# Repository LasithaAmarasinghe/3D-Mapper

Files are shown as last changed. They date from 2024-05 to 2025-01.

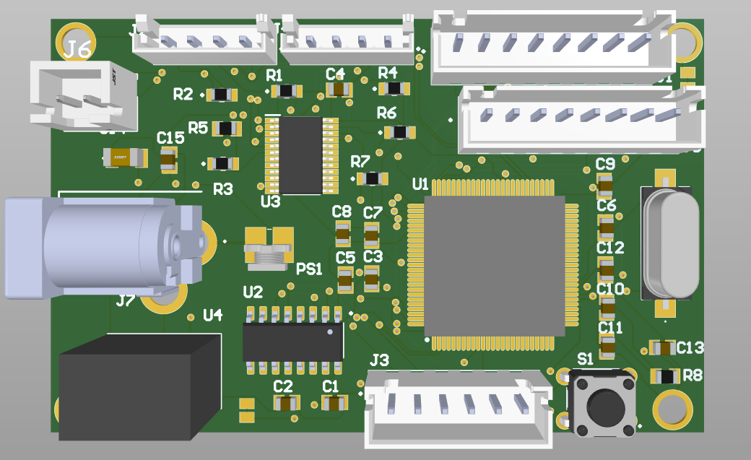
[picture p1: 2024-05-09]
PCB design/3D view.png

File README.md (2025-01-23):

# 3D-Mapper 
* 3D-Mapper is a 3D plotting device made for short-range object detection powered by [ATmega 2560](https://github.com/LasithaAmarasinghe/3D-Mapper/blob/main/data%20sheets/ATMEGA2560.PDF).
* This is developed for the semester 4 project under EN 2160: Electronic Design Realization.


## Working Principle 

* This device measures distances to objects using two Time-of-Flight (TOF) sensors, which are rotated by two stepper motors to cover the entire 3D environment.
* The distance values are saved in (r, theta, alpha) coordinates and then converted to (x, y, z) coordinates.
* Using the [PyVista](https://github.com/pyvista) library in Python, a 3D point cloud is generated from these cartesian coordinates. 
* A tetrahedral mesh is created by performing [3D Delaunay triangulation](https://github.com/LasithaAmarasinghe/3D-Mapper/blob/main/3D%20Delaunay%20Triangulation.pdf) on the point cloud.
* Then the outer surface of this tetrahedral mesh is extracted to form a surface mesh.

## Why "3D-Mapper"?

* Precision in Short-Range Mapping
* Comprehensive Coverage
* Cost-Effective
* Scalability and Customization
* Versatility Across Industries

## Areas of Opportunity

* Emerging Technology Integration - Enhance capabilities with AI and machine learning.
* Market Expansion - Adapt for use in virtual reality (VR) & augmented reality (AR) to access new and growing markets.
* Data Analytics Enhancement - Develop advanced software for better data analysis and visualization, adding value and creating new revenue streams.

## Hardware Specifications

* [ATmega2560](https://github.com/LasithaAmarasinghe/3D-Mapper/blob/main/data%20sheets/ATMEGA2560.PDF)
* [CH340C USB to Serial Chip](https://github.com/LasithaAmarasinghe/3D-Mapper/blob/main/data%20sheets/CH340C%20USB%20to%20serial%20chip.PDF)
* [I2C Multiplexer](https://github.com/LasithaAmarasinghe/3D-Mapper/blob/main/data%20sheets/tca9548a%20I2C%20multiplexer.pdf)
* [Nema 17 Stepper Motors](https://github.com/LasithaAmarasinghe/3D-Mapper/blob/main/data%20sheets/NEMA17%20Stepper%20Motor.PDF)
* [Micro Step Motor Drivers](https://github.com/LasithaAmarasinghe/3D-Mapper/blob/main/data%20sheets/TB6600-Micro%20Step%20Stepper-Motor-Driver.pdf)
* [TOF Sensors](https://github.com/LasithaAmarasinghe/3D-Mapper/blob/main/data%20sheets/TOF.png)
* [12V to 5V Buck Converter](https://github.com/LasithaAmarasinghe/3D-Mapper/blob/main/data%20sheets/R_78CK_0_5-DC_DC%20Converter.pdf)

## Software Specifications

* Arduino IDE
* Solid Works
* Altium
* Python 











## PCB Design



## PCB 

PCB

## Solidworks Design

solidworks
Interior Design
Side view

## Team

team

## For More Information  

- **[Design Document](Design_Document.pdf)**
- **[Design Methodology Report](Design_Methodology_Report.pdf)**

## License
 
 * This project is licensed under the MIT License. See the [LICENSE](MIT-LICENSE.txt) file for details.

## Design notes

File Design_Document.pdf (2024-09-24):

# Department of Electronic & Telecommunication

Engineering,
University of Moratuwa, Sri Lanka.

# 3D Mapping Device for Object Tracking Design Documentation - Group B

# Submitted By:

210728C Wijewickrama W.K.D.D.D. 210031H Amarasinghe A.A.W.L.R.

## Submitted in partial fulfillment of the requirements for the module

# EN 2160 : Electronic Design Realization

## 7th July 2024

EN2160 | Design Documentation : Group B

# Contents

1 Introduction | 3
2 Component Selection and Justifications | 4
3 Schematic Design | 17
4 PCB Design | 26
5 Enclosure Design | 31
6 Detailed Programming Information | 40
7 Photographs | 62
8 References | 80

1

9 Signed Declaration | 81
10 Appendix | 82

2

# 1 Introduction

The 3D Scanner device represents a cutting-edge solution for precise and efficient three-dimensional data acquisition in various applications. This design document comprehensively outlines the component selection process and daily progress of the project. It encapsulates the combined work of our multi-disciplinary team, leveraging expertise in optical engineering, electronics, software development, and human-centered design principles.
The device features a Time-of-Flight (ToF) sensor designed for precise measurement of distances and angles. It utilizes UART communication via ATMEGA 2560 microcontroller pins connected to a USB-to-Serial converter, enabling seamless interfacing with computers equipped with USB ports for data transmission and visualization. This setup ensures efficient handling of distance measurement data and robust communication capabilities, making the device suitable for applications requiring

## accurate spatial data acquisition and analysis

3

# 2 Component Selection and Justifications

## 2.1 Microcontroller

## ATMEGA 2560 MCU

- The ATMEGA 2560 microcontroller unit (MCU) was selected as the central processing unit for the 3D surround scanner. This microcontroller was chosen for its adequate memory, processing speed, and overall reliability.

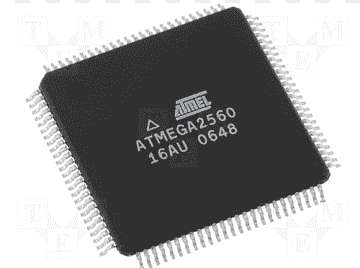
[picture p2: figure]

## Figure 1: ATmega 2560

## Specifications:

## - High Performance, Low Power AVR® 8-Bit Microcontroller

## - Advanced RISC Architecture

## - Non-volatile Program and Data Memories

## - JTAG (IEEE std. 1149.1 compliant) Interface

## - 51/86 Programmable I/O Lines

## - Temperature Range: -40°C to 85°C Industrial

## Key Features:

## - Memory: The ATMEGA 2560 offers 256 KB of Flash memory, 8 KB of SRAM, and 4 KB of

EEPROM, providing sufficient space for handling the initial stages of data processing.

## - Processing Speed: It operates at a clock speed of 16 MHz, which meets the demands of

real-time data collection and processing required for the 3D mapper.

- Reliability: Known for its stable performance, the ATMEGA 2560 is widely used in various applications, making it a dependable choice for our project.

4

## Reasons for Selection:

- Versatility: The ATMEGA 2560 supports a wide range of peripherals and interfaces, making it adaptable to various components used in the 3D mapper project.

## - Community Support: The ATMEGA 2560 has extensive documentation and a large commu-

nity of users, providing valuable resources and support for troubleshooting and development.

- Cost-Effective: Compared to other microcontrollers with similar capabilities, the ATMEGA 2560 offers a good balance between performance and cost, making it an economical choice for the project.

## - Ease of Programming: The microcontroller is compatible with the Arduino platform, which

simplifies programming and prototyping, allowing for faster development cycles.

- Proven Track Record: The ATMEGA 2560 has been used in numerous successful projects, indicating its reliability and robustness in real-world applications.

Despite these advantages, the memory capacity of the ATMEGA 2560 was insufficient to store the entire dataset generated during the scanning process. Therefore, the data readings had to be transmitted incrementally to a connected computer for further processing and storage.

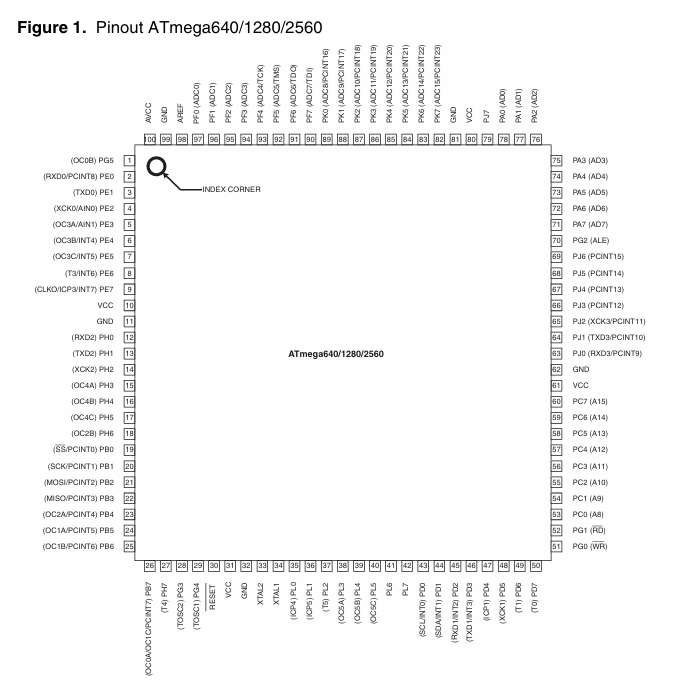
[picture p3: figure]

## Figure 2: ATmega2560

5

## 2.2 Time-of-Flight (ToF) Sensors

## VL53L0 ToF Sensors

- Two Time-of-Flight sensors were selected for the 3D mapper to measure the distance of objects with high precision and speed.

## Figure 3: TOF

## Specifications

- VDD: Regulated 2.8 V output. Almost 150 mA available to power external components.
- VIN: The main 2.6 V to 5.5 V power supply connection. The SCL and SDA level shifters pull the I2C wire high to this level.

## - GND: The ground (0 V) connection for power supply. I2C control source must also share a

common ground with this board.

- SDA: Level-shifted I2C data line; HIGH is VIN, LOW is 0 V.
- SCL: Level-shifted I2C clock line; HIGH is VIN, LOW is 0 V.

## - XSHUT: This pin is an active-low shutdown input; the board pulls it up to VDD to enable

the sensor by default.

## Reasons for Selection:

- High Precision: ToF sensors are capable of measuring distances accurately, which is crucial for creating a detailed 3D map.
- Speed: These sensors can take measurements rapidly, enabling real-time data collection and processing.
- Range: ToF sensors can cover a sufficient range suitable for the intended mapping application.

6

## 2.3 I2C Multiplexer

## TCA9548A

- An I2C multiplexer was used to connect the two ToF sensors to the ATMEGA 2560.

## Figure 4: TCA9548A

## Specifications:

## - 1-to-8 Bidirectional Translating Switches

## - I2C Bus and SMBus Compatible

## - Allows Voltage-Level Translation Between 1.8-V, 2.5-V, 3.3-V, and 5-V Buses

## - Operating Power-Supply Voltage Range of 1.65-V to 5.5-V

## - Low RON Switches

## Reasons for Selection:

## - Multiple I2C Devices: The multiplexer allows multiple I2C devices to be connected to a

single I2C bus, expanding the number of sensors that can be used simultaneously.

- Simplifies Wiring: Reduces the complexity of wiring by allowing easy addition of sensors without requiring additional I2C ports on the microcontroller.

## - Efficient Communication: Ensures efficient communication between the microcontroller

and the sensors, maintaining the integrity and speed of data transfer.

7

## 2.4 USB Serial Communication

## CH340C

## - The CH340C chip was chosen for USB serial communication between the ATMEGA 2560 and

the connected computer.

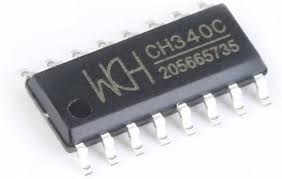
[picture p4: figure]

## Figure 5: CH340C

## Specifications:

## - Full-speed USB device interface, compatible with USB V2.0

## - Fully compatible with serial port applications

## - Supports common MODEM contact signals

## - Provides RS232, RS485, RS422 interfaces

## - Supports 5V and 3.3V power supply voltages

## Reasons for Selection:

- Reliable Communication: Provides a reliable interface for serial communication over USB, essential for transmitting data to the computer for further processing.
- Compatibility: Compatible with a wide range of operating systems, ensuring ease of integration and use.
- Cost-Effective: The CH340C is a cost-effective solution for USB to serial conversion, making it an economical choice for the project.

8

## 2.5 Stepper Motor

## Nema 17HS4401

- The NEMA 17HS4401 stepper motor is renowned for its versatility and reliability in various

## applications requiring precise motion control

## Figure 6: Nema 17

## Specifications

- Holding Torque: 0.35 Nm at continuous current, 0.5 Nm at peak current.
- Continuous Output Current: 1.8 A.
- Step Angle: 1.8°.
- Rotor Inertia: 57 g·cm².
- Weight: 0.37 kg.

## Reasons for Selection

1. Compact Size: Suitable for applications with limited space, such as 3D printers and small CNC machines.
2. Moderate Torque: Provides adequate torque (0.35 Nm continuous, 0.5 Nm peak) for precise motion control and handling moderate loads.
3. Precise Control: 1.8° step angle and high subdivision accuracy (1–32 steps) enable fine resolution and accurate positioning.
4. Versatility: Compatible with various driver modules and control systems, offering flexibility in design and integration.
5. Cost-Effectiveness: Balances performance and cost effectiveness, making it a practical choice for both industrial and DIY projects.
6. Reliability: Known for robust construction and durability, ensuring reliable performance in demanding environments.
7. Availability: Widely available from multiple manufacturers, providing easy access to parts and support.

9

## Calculation for Selection

10

11

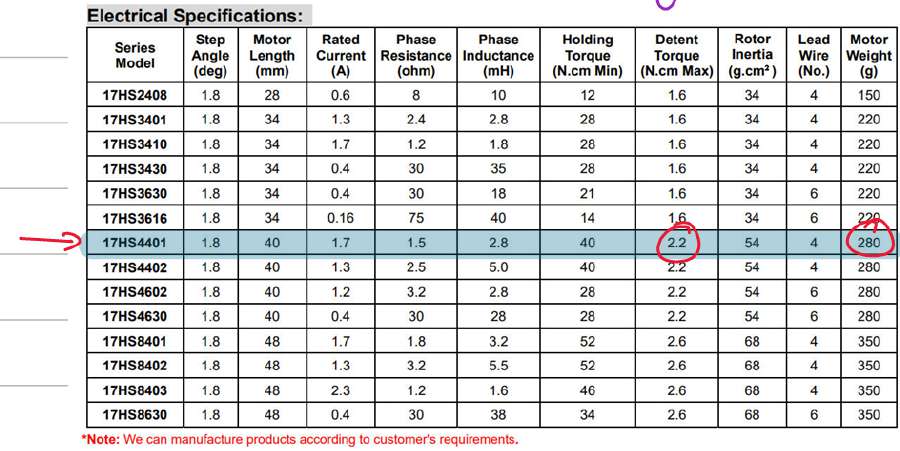
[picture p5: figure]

## Figure 7: Nema17 Motor Comparision

Other constraints of choosing a suitable stepper motor were availability and price within budget. So we decided Nema 17HS4401 as the best option for the 3D scanner considering all the factors.

12

## 2.6 Stepper Motor Driver

TB6600
- The TB6600 stepper motor driver is a versatile choice for controlling stepper motors in various applications. It offers a range of features suitable for precise and powerful motor control, making it ideal for both industrial and DIY projects.

## Figure 8: TB6600

## Specifications:

## - Model: TB6600

## - Compatible Motors: Nema 17/23/34 (42/57/86 Stepper Motor)

## - Control Signal: 3.3VDC–24VDC

## - Subdivision Accuracy: 1–32

## - Output Current: 4A

## - Voltage: 9VDC–40VDC

## Reasons for Selection:

- Motor Compatibility: Compatible with Nema 17, 23, 34 motors.
- Output Current: Up to 4A for sufficient torque.
- Voltage Range: Supports 9VDC–40VDC for flexible power options.
- Subdivision Accuracy: Precision from 1–32 steps.
- Control Signal: Compatible with 3.3VDC–24VDC signals.
- Reliability: Known for robust performance in industrial applications.

13

## 2.7 Power Step-Down

## R-78CK-0.5 12V-5V

## - A 12V-5V power step-down module was used to supply power to the ATMEGA 2560 and other

components.

## Figure 9: R-78CK-0.5

## Specifications

## - Efficiency up to 96%

## - Pin-out compatible with LM78xx linears

## - Compact package

## - Wide input range (5V - 40V)

## - Short circuit protection, thermal shutdown

## - Low ripple and noise

## Reasons for Selection:

- Voltage Regulation: Ensures stable voltage supply to the microcontroller and sensors, which is crucial for reliable operation.
- Efficiency: High efficiency in converting 12V input to 5V output, minimizing power loss and heat generation.
- Compact Size: The module is compact, making it easy to integrate into the overall design without adding significant bulk.

14

## 2.8 Clock Oscillator

## 16 MHz Crystal Oscillator

- A 16 MHz crystal oscillator was used to provide the clock signal for the ATMEGA 2560.

## Figure 10: oscillator

## Specifications

## - Model: HC49/4HSMX

## - Frequency: 16 MHz

## - Load Capacitance: 22 pF

## - Shunt Capacitance: 7pF max

## - Tolerance: 30 PPM

## - Frequency Stability: 50 PPM

## - Overtone Order: Fundamental

## Reasons for Selection:

## - Precision Timing: Provides a stable and precise clock signal necessary for the accurate

operation of the microcontroller.

- Frequency Stability: Ensures consistent performance of the microcontroller by maintaining a stable clock frequency.

## - Compatibility: Specifically chosen to match the operational requirements of the ATMEGA

2560.

15

## 2.9 Decoupling Capacitors

## 100µF Decoupling Capacitors

- 100µF decoupling capacitors were used to stabilize the power supply to the microcontroller and other components.

## Figure 11: capacitor

## Reasons for Selection:

- Noise Reduction: Help to filter out noise and prevent voltage spikes, ensuring a stable power supply.

## - Improved Performance: Enhances the overall performance and reliability of the microcon-

troller by maintaining a clean power signal.

- Protection: Protects sensitive components from transient voltage fluctuations.

## 2.10 Pull-up Resistors

## 2.2k Resistors

- 2.2k resistors were used in the I2C lines to ensure proper signal levels.

## Figure 12: resistor

## Reasons for Selection:

- Pull-up Function: These resistors act as pull-up resistors for the I2C bus, ensuring that the lines are correctly biased and that signals are accurately interpreted.
- Signal Integrity: Maintains the integrity of the I2C signals, preventing erroneous data transmission.
- Standard Value: 2.2k ohms is a standard value for pull-up resistors in I2C communication, ensuring compatibility and reliable operation.

16

# 3 Schematic Design

The schematic design for the overall system was developed using the Altium Designer EDA platform. To ensure an organized and efficient design process, we adopted a hierarchical design methodology,

## emphasizing modularity and abstraction where we identified four main sub-parts:

## 1. Microcontroller Circuit

## 2. USB Port Circuit

## 3. I2C Multiplexer Circuit

## 4. Power Supply Circuit

## 3.1 System Overview

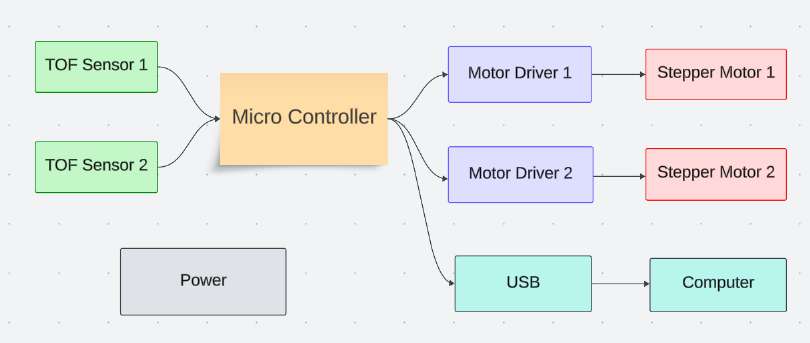
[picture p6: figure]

## Figure 13: block diagram

## The system consists of the following components and their interactions:

## - Microcontroller:

## – Receives data from TOF sensors

– Send control signals to stepper motors.

## - TOF Sensors:

– Measure distance to objects.

– Send distance data to the microcontroller.

## - Stepper Motor Drivers:

– Receive signals from the microcontroller.

– Control the rotation of stepper motors based on these signals.

## - Stepper Motors:

– Rotate according to commands given by the motor drivers.

## - USB Port:

– Transfers distance data from the microcontroller to the computer.

17

## Figure 14: Main

18

## 3.2 Microcontroller Circuit

The microcontroller circuit is designed with the ATmega2560 as the core of the device.

## - Microcontroller:

– Used the ATmega2560, an 8-bit microcontroller.

– Features 256K Bytes of In-System Programmable Flash memory. – Includes 54 digital I/O pins for versatile connectivity and control.

– Ideal for memory-intensive applications.

## Figure 15: ATmega2560

## - Connections:

– CH340C chip is connected to the MCU for USB-to-serial communication.

– I2C multiplexer is connected to the MCU for handling multiple I2C devices.

– Two stepper motor drivers are connected to the MCU to provide ENABLE, DIRECTION, and PULL commands.

19

## - Clocking:

– Included a 16 MHz crystal oscillator for accurate clocking.

– Stabilized the oscillator with capacitors to ensure precise frequency and reliable operation.

## Figure 16: oscilator

## - Noise Reduction & Stabilization:

– Added decoupling capacitors to reduce noise and ensure stable operation.

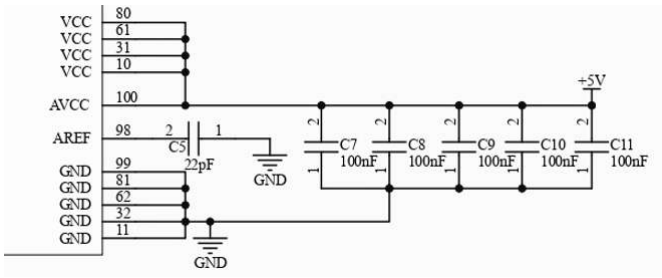
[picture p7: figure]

## Figure 17: capacitors

20

## Figure 18: MCU circuit

21

## 3.3 USB Port Circuit

- Utilizes the CH340C USB-to-serial converter.

- Facilitates reliable data transfer to a computer.
- Proper decoupling capacitors for stable operation.
- Ensures compatibility with various operating systems through the CH340C driver.
- Provides stable and reliable communication between the microcontroller and the computer.
- Receiver and transmitter pins of CH340C chip is connected with transmitter and receiver of atmega 2560.

## Figure 19: CH340

## Figure 20: USB port circuit

22

## 3.4 I2C Multiplexer Circuit

- The I2C multiplexer circuit is designed to get data from two TOF sensors simultaneously.

- The multiplexer can support up to 8 I2C communication devices.
- Two TOF sensors are connected to the I2C multiplexer with SD0,SC0,SD1,SD1 ports.

## - Pull-up resistors are used on the I2C lines to ensure proper communication:

## – Ensures that the SDA (data) and SCL (clock) lines are pulled to a high logic level when

not actively driven low.
– Helps to avoid floating states and improves the reliability of the communication.

## Figure 21: I2C multiplexer

## Figure 22: I2C multiplexer circuit

23

## 3.5 Power Supply Circuit

## - Designed to provide a stable 5V supply from the 12V supply

## - External 12V 10A SMPS Large Power Supply converts 230VAC to 12VDC and supplies to the power supply circuit

- R-78CK-0.5 ,non-isolated DC-DC converter converts 12V to 5V.

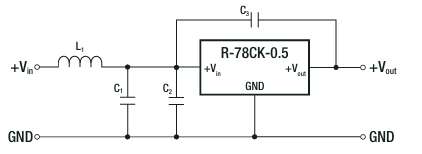
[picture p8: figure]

## Figure 23: R-78CK-0.5

## Figure 24: Power supply circuit

This approach allowed for clear separation of different functional blocks, making the design more manageable and easier to troubleshoot. We planned to use Surface Mount Devices. During the design process, we referred to component selection platforms such as Mouser and LCSC. This enabled seamless integration of component footprints directly into our design, ensuring that all selected components were compatible with the SMD process.

24

## 3.6 Bill of Materials

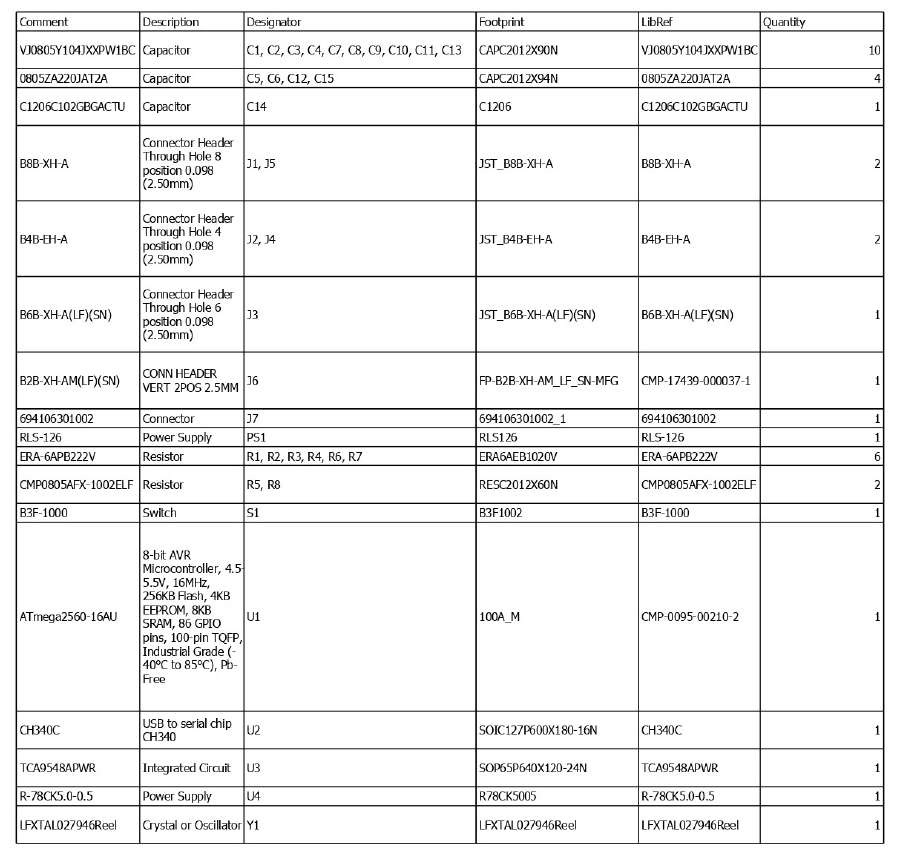
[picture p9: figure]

## Figure 25: BOM

25

# 4 PCB Design

The PCB layout integrates all schematic designs onto a single board, ensuring optimal component placement and efficient signal routing. Our design process prioritizes robustness, reliability, and ease of integration.

- Trace width: A trace width of 0.3 mm is chosen for signal traces, while a width of 0.4 mm is used for power components, ensuring adequate power delivery and signal integrity.

## - PCB Size: 1650mil * 2615mil ( 4.20cm * 6.64cm )

- Component Placement: Components are strategically positioned to minimize trace lengths and optimize signal paths. Critical components such as the microcontroller and ICs are centrally located to enhance stability and performance. Decoupling capacitors are placed close to the ICs to filter out noise and provide a stable power supply.
- Use of vias: Vias of sufficient diameter are used to transition traces between the top and bottom layers of the PCB.

## Figure 26: trace width calculation

26

## 4.1 PCB

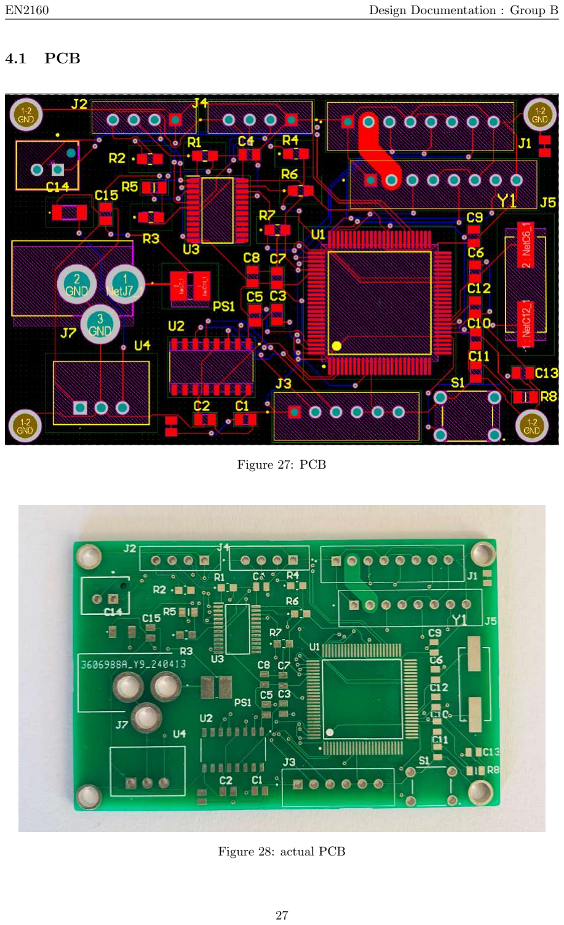
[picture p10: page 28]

## Figure 27: PCB

## Figure 28: actual PCB

27

## 4.2 Top Layer

## Figure 29: Top Layer

## 4.3 Bottom Layer

## Figure 30: Bottom Layer

28

## 4.4 Overlay Layer

## Figure 31: Overlay Layer

## 4.5 Drill Drawings

## Figure 32: Drill Drawings

29

## 4.6 3D View

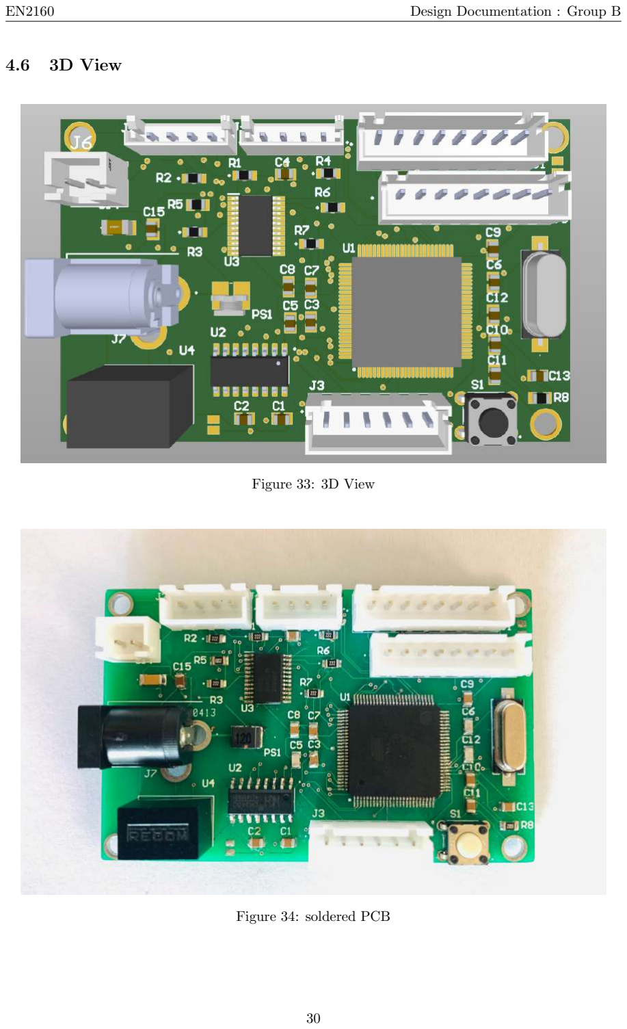
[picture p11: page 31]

## Figure 33: 3D View

## Figure 34: soldered PCB

30

# 5 Enclosure Design

The 3D model for the enclosure of the Vibration Damping System is designed using SolidWorks 2020, a common and parametric 3D CAD tool known for its robust product data management capabilities. This software allows for seamless updates to the design, ensuring that modifications can be made without compromising the initial specifications.

## 5.1 CAD Tool: SolidWorks 2020

Description: SolidWorks 2020 is utilized for designing the enclosure due to its advanced parametric modeling features and comprehensive product data management. This choice allows for efficient design iterations and ensures that any changes can be easily managed and tracked.

## Advantages:

- Parametric Design: Facilitates easy modifications by adjusting design parameters.
- Product Data Management: Ensures consistency and traceability of design changes, maintaining the integrity of the original specifications.

## 5.2 Material: PLA+

Description: The enclosure is made from PLA+ (Polylactic Acid Plus), a durable and eco-friendly plastic known for its enhanced properties compared to standard PLA. It provides the necessary strength while being lightweight.

## Specifications:

1. Weight: The initial enclosure weighs 50g.
2. Draft Angles: The enclosure features 1-degree draft angles to facilitate easy removal from molds during manufacturing.

## 3. Thickness: The design maintains a minimum thickness of 3 mm, which is greater than the

moldable thickness range for PLA+.

31

## 5.3 Bottom Part

## Figure 35: Enclosure

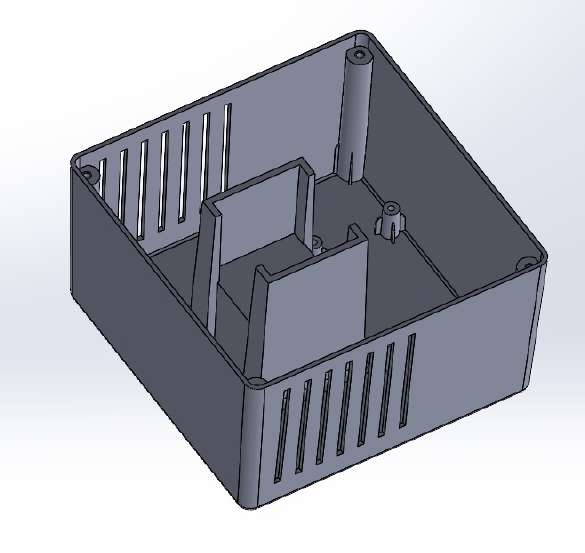
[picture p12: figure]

## Figure 36: Side View

32

## Figure 37: Top View

## Figure 38: Top View with Components

33

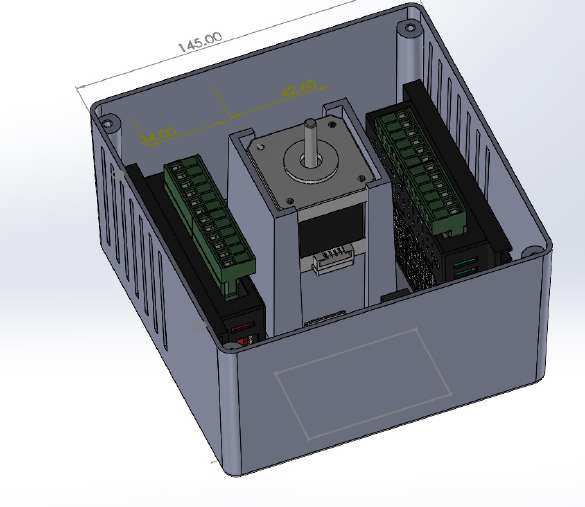
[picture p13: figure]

## Figure 39: Side View with Components

34

## Figure 40: Model Tree - Bottom Part

35

## 5.4 Top Part

## Figure 41: top view

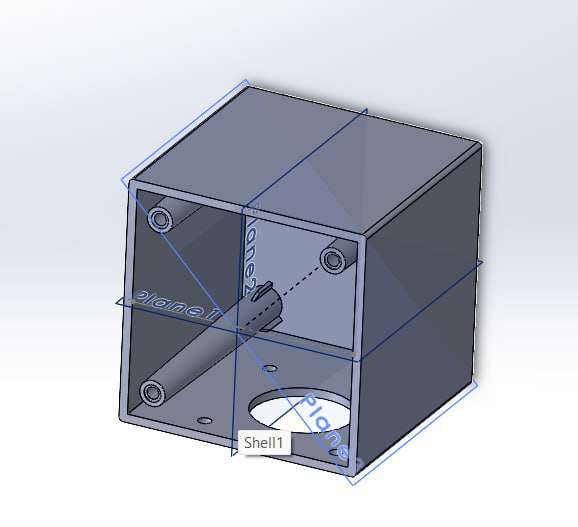
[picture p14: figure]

## Figure 42: isometric view

36

## Figure 43: model tree - top part

37

## 5.5 Lid

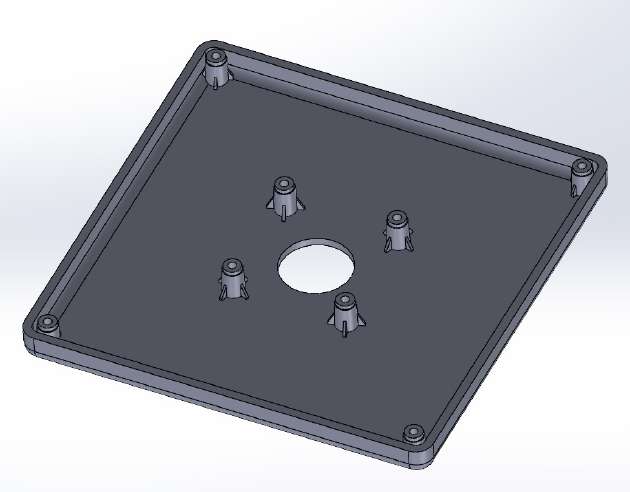
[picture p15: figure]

## Figure 44: Side View

## Figure 45: Inside Lid

38

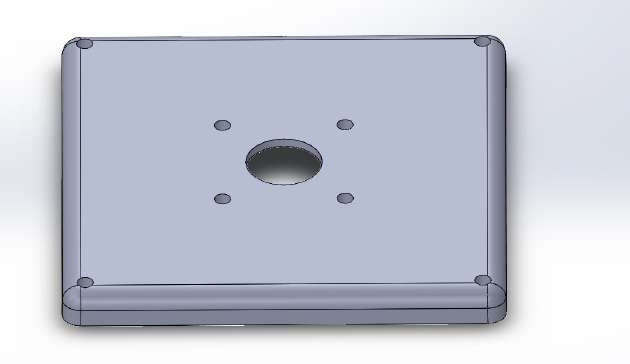
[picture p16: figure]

## Figure 46: Outside Lid

## 5.6 TOF holder

## Figure 47: TOF holder

39

# 6 Detailed Programming Information

## 6.1 C++ Code for the Micro-controller

1 | # include <avr /io.h>
2 | # include <util / delay .h>
3 | # include <avr / interrupt .h>
4 | # include " VL53L0X .h"

5
6 | # define STEP_PIN_1 24
7 | # define DIR_PIN_1 23
8 | # define ENA_PIN_1 22

9
10 | # define STEP_PIN_2 27
11 | # define DIR_PIN_2 26
12 | # define ENA_PIN_2 25

13
14 | # define XY_REV 200
15 | # define XZ_REV 50

16
17 # define ANGLE_INCREMENT 1.8

18
19 | # define F_CPU 16000000 UL // Assuming a 16 MHz clock
20 | # define BAUD 9600
21 | # define MYUBRR F_CPU /16/ BAUD -1

22
23 | # define F_SCL 100000 UL // SCL frequency
24 | # define Prescaler 1
25 | # define TWBR_val (((( F_CPU / F_SCL ) / Prescaler ) - 16) / 2)

26
27 float measurements [ XZ_REV ][3];

28
29 | void uart_init ( unsigned int ubrr ) {
30 | // Set baud rate
31 | UBRR0H = ( unsigned char )( ubrr >> 8) ;
32 | UBRR0L = ( unsigned char ) ubrr ;
33 | // Enable receiver and transmitter
34 | UCSR0B = (1 << RXEN0 ) | (1 << TXEN0 );
35 | // Set frame format : 8 data bits , 1 stop bit
36 | UCSR0C = (1 << UCSZ01 ) | (1 << UCSZ00 ) ;
37 | }

38
39 | void uart_transmit ( unsigned char data ) {
40 | // Wait for empty transmit buffer
41 | while (!( UCSR0A & (1 << UDRE0 )) );
42 | // Put data into buffer , sends the data
43 | UDR0 = data ;
44 | }

45
46 | void uart_print ( const char * str ) {
47 | while (* str ) {
48 | uart_transmit (* str ++) ;
49 | }
50 | }

51
52 | void i2c_init ( void ) {
53 | TWSR = 0 x00 ;
54 | TWBR = ( uint8_t ) TWBR_val ;
55 | }

56
57 | void i2c_start ( void ) {
58 | TWCR = (1 << TWINT ) | (1 << TWSTA ) | (1 << TWEN );
59 | while (!( TWCR & (1 << TWINT )));
60 | }

61
62 | void i2c_stop ( void ) {
63 | TWCR = (1 << TWINT ) | (1 << TWSTO ) | (1 << TWEN );

40

64 | while ( TWCR & (1 << TWSTO ) );
65 | }

66
67 | void i2c_write ( uint8_t data ) {
68 | TWDR = data ;
69 | TWCR = (1 << TWINT ) | (1 << TWEN ) ;
70 | while (!( TWCR & (1 << TWINT )));
71 | }

72
73 | uint8_t i2c_read_ack ( void ) {
74 | TWCR = (1 << TWINT ) | (1 << TWEN ) | (1 << TWEA );
75 | while (!( TWCR & (1 << TWINT )));
76 | return TWDR ;
77 | }

78
79 | uint8_t i2c_read_nack ( void ) {
80 | TWCR = (1 << TWINT ) | (1 << TWEN ) ;
81 | while (!( TWCR & (1 << TWINT )));
82 | return TWDR ;
83 | }

84
85 | void tof ( uint8_t bus ) {
86 | i2c_start () ;
87 | i2c_write (0 x70 << 1) ; // TCA9548A address is 0 x70
88 | i2c_write (1 << bus ); | // send byte to select bus
89 | i2c_stop () ;
90 | }

91
92 | void setup () {
93 | uart_init ( MYUBRR ); | // Initialize the UART
94 | i2c_init () ; | // Initialize I2C

95
96 | tof (1) ;

97
98 | // Set pin modes using direct port manipulation
99 | DDRB |= (1 << DDB0 ) | (1 << DDB1 ) | (1 << DDB2 ); // STEP_PIN_1 , DIR_PIN_1 ,
| ENA_PIN_1
100 | DDRB |= (1 << DDB3 ) | (1 << DDB4 ) | (1 << DDB5 ); // STEP_PIN_2 , DIR_PIN_2 ,
| ENA_PIN_2

101
102 | // Enable pins
103 | PORTB &= ~(1 << PORTB2 ) ; // ENA_PIN_1 LOW
104 | PORTB &= ~(1 << PORTB5 ) ; // ENA_PIN_2 LOW

105
106 | // Move to the starting position
107 | PORTB &= ~(1 << PORTB4 ) ; // DIR_PIN_2 LOW
108 | for (int i = 0; i < XZ_REV / 2; i ++) {
109 | PORTB |= (1 << PORTB3 ); // STEP_PIN_2 HIGH
110 | PORTB &= ~(1 << PORTB3 ) ; // STEP_PIN_2 LOW
111 | delayMicroseconds (50) ;
112 | }

113
114 | uart_print (" VL53L0X test with Stepper Motor \n");
115 | }

116
117 | void loop () {
118 | for (int i = 0; i < XY_REV ; i ++) {
119 | if (i % 2 == 0) {
120 | PORTB |= (1 << PORTB4 ); // DIR_PIN_2 HIGH
121 | } else {
122 | PORTB &= ~(1 << PORTB4 ) ; // DIR_PIN_2 LOW
123 | }
124 | for (int j = 0; j < XZ_REV ; j ++) {
125 | i2c_start () ;
126 | i2c_write (0 x29 << 1) ; // VL53L0X address
127 | i2c_write (0 x00 ); // Register to read
128 | i2c_start () ;
129 | i2c_write ((0 x29 << 1) | 1) ; // Read mode

41

130 | uint8_t range = i2c_read_nack () ;
131 | i2c_stop () ;

132
133 | if (i % 2 == 0) {
134 | if ( range != 255) { | // Check if range is valid
135 | measurements [j ][0] = j * ANGLE_INCREMENT - 45;
136 | measurements [j ][1] = i * ANGLE_INCREMENT ;
137 | measurements [j ][2] = range ;
138 | } else {
139 | measurements [j ][0] = j * ANGLE_INCREMENT - 45;
140 | measurements [j ][1] = i * ANGLE_INCREMENT ;
141 | measurements [j ][2] = 10000;
142 | }
143 | } else {
144 | if ( range != 255) { | // Check if range is valid
145 | measurements [ XZ_REV - j - 1][0] = j * ANGLE_INCREMENT - 45;
146 | measurements [ XZ_REV - j - 1][1] = i * ANGLE_INCREMENT ;
147 | measurements [ XZ_REV - j - 1][2] = range ;
148 | } else {
149 | measurements [ XZ_REV - j - 1][0] = j * ANGLE_INCREMENT - 45;
150 | measurements [ XZ_REV - j - 1][1] = i * ANGLE_INCREMENT ;
151 | measurements [ XZ_REV - j - 1][2] = 10000;
152 | }
153 | }
154 | PORTB |= (1 << PORTB3 ); // STEP_PIN_2 HIGH
155 | PORTB &= ~(1 << PORTB3 ) ; // STEP_PIN_2 LOW
156 | }
157 | uart_print (" aaa [");
158 | for (int k = 0; k < XZ_REV ; k ++) {
159 | uart_transmit (’[’);
160 | uart_print ( measurements [ k ][0]) ;
161 | uart_transmit (’,’);
162 | uart_print ( measurements [ k ][1]) ;
163 | uart_transmit (’,’);
164 | uart_print ( measurements [ k ][2]) ;
165 | uart_transmit (’]’);
166 | if (k < XZ_REV - 1) uart_transmit (’,’);
167 | }
168 | uart_print ("]\n");
169 | PORTB |= (1 << PORTB0 ); // STEP_PIN_1 HIGH
170 | PORTB &= ~(1 << PORTB0 ) ; // STEP_PIN_1 LOW
171 | }
172 | }

42

## 6.2 C++ Code for vl53l0x.h library

To use the specific VL53L0X sensor, the manufacturer (Pololu Cooperation - A renowned company for sensor manufacturing) had implemented some specific bit sequences for I2C communication between the microcontroller and the sensor. Therefore they have recommended to use their own Open-Source and free to use pure C-AVR library to use that sensor. Therefore we implemented only that part as a usage of external library according to the recommendation of the manufacturer. But here we have included the complete source code for that sensor data reading.

1 // Copyright (c) 2017 -2022 Pololu Corporation .

2
3 | // For more information , see
4 | // https :// www . pololu . com /
5 | // https :// forum . pololu .com/

6
7 | // Permission is hereby granted , free of charge , to any person
8 | // obtaining a copy of this software and associated documentation
9 | // files ( the " Software ") , to deal in the Software without
10 | // restriction , including without limitation the rights to use ,
11 | // copy , modify , merge , publish , distribute , sublicense , and/or sell
12 | // copies of the Software , and to permit persons to whom the
13 | // Software is furnished to do so , subject to the following
14 | // conditions :

15
16 | // The above copyright notice and this permission notice shall be
17 | // included in all copies or substantial portions of the Software .

18
19 | // THE SOFTWARE IS PROVIDED "AS IS" , WITHOUT WARRANTY OF ANY KIND ,
20 | // EXPRESS OR IMPLIED , INCLUDING BUT NOT LIMITED TO THE WARRANTIES
21 | // OF MERCHANTABILITY , FITNESS FOR A PARTICULAR PURPOSE AND
22 | // NONINFRINGEMENT . IN NO EVENT SHALL THE AUTHORS OR COPYRIGHT
23 | // HOLDERS BE LIABLE FOR ANY CLAIM , DAMAGES OR OTHER LIABILITY ,
24 | // WHETHER IN AN ACTION OF CONTRACT , TORT OR OTHERWISE , ARISING
25 | // FROM , OUT OF OR IN CONNECTION WITH THE SOFTWARE OR THE USE OR
26 | // OTHER DEALINGS IN THE SOFTWARE .

27
28 // =================================================================

29
30 | // Most of the functionality of this library is based on the VL53L0X API
31 | // provided by ST (STSW - IMG005 ), and some of the explanatory comments are quoted
32 | // or paraphrased from the API source code , API user manual ( UM2039 ), and the
33 | // VL53L0X datasheet .

34
35 | # include " VL53L0X .h"
36 | # include <Wire .h>

37
38 // Defines /////////////////////////////////////////////////////////////////////

39
40 | // The Arduino two - wire interface uses a 7- bit number for the address ,
41 | // and sets the last bit correctly based on reads and writes
42 | # define ADDRESS_DEFAULT 0 b0101001

43
44 | // Record the current time to check an upcoming timeout against
45 | # define startTimeout () ( timeout_start_ms = millis ())

46
47 | // Check if timeout is enabled ( set to nonzero value ) and has expired
48 | # define checkTimeoutExpired () ( io_timeout > 0 && (( uint16_t )( millis () -
| timeout_start_ms ) > io_timeout ))

49
50 | // Decode VCSEL ( vertical cavity surface emitting laser ) pulse period in PCLKs
51 | // from register value
52 | // based on VL53L0X_decode_vcsel_period ()
53 | # define decodeVcselPeriod ( reg_val ) | ((( reg_val ) + 1) << 1)

54
55 | // Encode VCSEL pulse period register value from period in PCLKs
56 | // based on VL53L0X_encode_vcsel_period ()
57 | # define encodeVcselPeriod ( period_pclks ) ((( period_pclks ) >> 1) - 1)

43

58
59 | // Calculate macro period in * nanoseconds * from VCSEL period in PCLKs
60 | // based on VL53L0X_calc_macro_period_ps ()
61 | // PLL_period_ps = 1655; macro_period_vclks = 2304
62 | # define calcMacroPeriod ( vcsel_period_pclks ) (((( uint32_t ) 2304 * ( vcsel_period_pclks )
| * 1655) + 500) / 1000)

63
64 // Constructors ////////////////////////////////////////////////////////////////

65
66 | VL53L0X :: VL53L0X ()
67 | : bus (& Wire )
68 | , address ( ADDRESS_DEFAULT )
69 | , io_timeout (0) // no timeout
70 | , did_timeout ( false )
71 | {
72 | }

73
74 // Public Methods //////////////////////////////////////////////////////////////

75
76 | void VL53L0X :: setAddress ( uint8_t new_addr )
77 | {
78 | writeReg ( I2C_SLAVE_DEVICE_ADDRESS , new_addr & 0 x7F );
79 | address = new_addr ;
80 | }

81
82 | // Initialize sensor using sequence based on VL53L0X_DataInit () ,
83 | // VL53L0X_StaticInit () , and VL53L0X_PerformRefCalibration ().
84 | // This function does not perform reference SPAD calibration
85 | // ( VL53L0X_PerformRefSpadManagement ()), since the API user manual says that it
86 | // is performed by ST on the bare modules ; it seems like that should work well
87 | // enough unless a cover glass is added .
88 | // If io_2v8 ( optional ) is true or not given , the sensor is configured for 2V8
89 | // mode .
90 | bool VL53L0X :: init ( bool io_2v8 )
91 | {
92 | // check model ID register ( value specified in datasheet )
93 | if ( readReg ( IDENTIFICATION_MODEL_ID ) != 0 xEE ) { return false ; }

94
95 | // VL53L0X_DataInit () begin

96
97 | // sensor uses 1V8 mode for I/O by default ; switch to 2V8 mode if necessary
98 | if ( io_2v8 )
99 | {
100 | writeReg ( VHV_CONFIG_PAD_SCL_SDA__EXTSUP_HV ,
101 | readReg ( VHV_CONFIG_PAD_SCL_SDA__EXTSUP_HV ) | 0 x01 ) ; // set bit 0
102 | }

103
104 | // " Set I2C standard mode "
105 | writeReg (0 x88 , 0 x00 );

106
107 | writeReg (0 x80 , 0 x01 );
108 | writeReg (0 xFF , 0 x01 );
109 | writeReg (0 x00 , 0 x00 );
110 | stop_variable = readReg (0 x91 );
111 | writeReg (0 x00 , 0 x01 );
112 | writeReg (0 xFF , 0 x00 );
113 | writeReg (0 x80 , 0 x00 );

114
115 | // disable SIGNAL_RATE_MSRC ( bit 1) and SIGNAL_RATE_PRE_RANGE ( bit 4) limit checks
116 | writeReg ( MSRC_CONFIG_CONTROL , readReg ( MSRC_CONFIG_CONTROL ) | 0 x12 ) ;

117
118 | // set final range signal rate limit to 0.25 MCPS ( million counts per second )
119 | setSignalRateLimit (0.25) ;

120
121 | writeReg ( SYSTEM_SEQUENCE_CONFIG , 0 xFF );

122
123 | // VL53L0X_DataInit () end

124

44

125 | // VL53L0X_StaticInit () begin

126
127 | uint8_t spad_count ;
128 | bool spad_type_is_aperture ;
129 | if (! getSpadInfo (& spad_count , & spad_type_is_aperture )) { return false ; }

130
131 | // The SPAD map ( RefGoodSpadMap ) is read by VL53L0X_get_info_from_device () in
132 | // the API , but the same data seems to be more easily readable from
133 | // GLOBAL_CONFIG_SPAD_ENABLES_REF_0 through _6 , so read it from there
134 | uint8_t ref_spad_map [6];
135 | readMulti ( GLOBAL_CONFIG_SPAD_ENABLES_REF_0 , ref_spad_map , 6) ;

136
137 | // -- VL53L0X_set_reference_spads () begin ( assume NVM values are valid )

138
139 | writeReg (0 xFF , 0 x01 );
140 | writeReg ( DYNAMIC_SPAD_REF_EN_START_OFFSET , 0 x00 );
141 | writeReg ( DYNAMIC_SPAD_NUM_REQUESTED_REF_SPAD , 0 x2C );
142 | writeReg (0 xFF , 0 x00 );
143 | writeReg ( GLOBAL_CONFIG_REF_EN_START_SELECT , 0 xB4 );

144
145 | uint8_t first_spad_to_enable = spad_type_is_aperture ? 12 : 0; // 12 is the first
| aperture spad
146 | uint8_t spads_enabled = 0;

147
148 | for ( uint8_t i = 0; i < 48; i ++)
149 | {
150 | if (i < first_spad_to_enable || spads_enabled == spad_count )
151 | {
152 | // This bit is lower than the first one that should be enabled , or
153 | // ( reference_spad_count ) bits have already been enabled , so zero this bit
154 | ref_spad_map [i / 8] &= ~(1 << (i % 8) ) ;
155 | }
156 | else if (( ref_spad_map [ i / 8] >> (i % 8) ) & 0 x1 )
157 | {
158 | spads_enabled ++;
159 | }
160 | }

161
162 | writeMulti ( GLOBAL_CONFIG_SPAD_ENABLES_REF_0 , ref_spad_map , 6) ;

163
164 | // -- VL53L0X_set_reference_spads () end

165
166 | // -- VL53L0X_load_tuning_settings () begin
167 | // DefaultTuningSettings from vl53l0x_tuning .h

168
169 | writeReg (0 xFF , 0 x01 );
170 | writeReg (0 x00 , 0 x00 );

171
172 | writeReg (0 xFF , 0 x00 );
173 | writeReg (0 x09 , 0 x00 );
174 | writeReg (0 x10 , 0 x00 );
175 | writeReg (0 x11 , 0 x00 );

176
177 | writeReg (0 x24 , 0 x01 );
178 | writeReg (0 x25 , 0 xFF );
179 | writeReg (0 x75 , 0 x00 );

180
181 | writeReg (0 xFF , 0 x01 );
182 | writeReg (0 x4E , 0 x2C );
183 | writeReg (0 x48 , 0 x00 );
184 | writeReg (0 x30 , 0 x20 );

185
186 | writeReg (0 xFF , 0 x00 );
187 | writeReg (0 x30 , 0 x09 );
188 | writeReg (0 x54 , 0 x00 );
189 | writeReg (0 x31 , 0 x04 );
190 | writeReg (0 x32 , 0 x03 );
191 | writeReg (0 x40 , 0 x83 );

45

192 | writeReg (0 x46 , 0 x25 );
193 | writeReg (0 x60 , 0 x00 );
194 | writeReg (0 x27 , 0 x00 );
195 | writeReg (0 x50 , 0 x06 );
196 | writeReg (0 x51 , 0 x00 );
197 | writeReg (0 x52 , 0 x96 );
198 | writeReg (0 x56 , 0 x08 );
199 | writeReg (0 x57 , 0 x30 );
200 | writeReg (0 x61 , 0 x00 );
201 | writeReg (0 x62 , 0 x00 );
202 | writeReg (0 x64 , 0 x00 );
203 | writeReg (0 x65 , 0 x00 );
204 | writeReg (0 x66 , 0 xA0 );

205
206 | writeReg (0 xFF , 0 x01 );
207 | writeReg (0 x22 , 0 x32 );
208 | writeReg (0 x47 , 0 x14 );
209 | writeReg (0 x49 , 0 xFF );
210 | writeReg (0 x4A , 0 x00 );

211
212 | writeReg (0 xFF , 0 x00 );
213 | writeReg (0 x7A , 0 x0A );
214 | writeReg (0 x7B , 0 x00 );
215 | writeReg (0 x78 , 0 x21 );

216
217 | writeReg (0 xFF , 0 x01 );
218 | writeReg (0 x23 , 0 x34 );
219 | writeReg (0 x42 , 0 x00 );
220 | writeReg (0 x44 , 0 xFF );
221 | writeReg (0 x45 , 0 x26 );
222 | writeReg (0 x46 , 0 x05 );
223 | writeReg (0 x40 , 0 x40 );
224 | writeReg (0 x0E , 0 x06 );
225 | writeReg (0 x20 , 0 x1A );
226 | writeReg (0 x43 , 0 x40 );

227
228 | writeReg (0 xFF , 0 x00 );
229 | writeReg (0 x34 , 0 x03 );
230 | writeReg (0 x35 , 0 x44 );

231
232 | writeReg (0 xFF , 0 x01 );
233 | writeReg (0 x31 , 0 x04 );
234 | writeReg (0 x4B , 0 x09 );
235 | writeReg (0 x4C , 0 x05 );
236 | writeReg (0 x4D , 0 x04 );

237
238 | writeReg (0 xFF , 0 x00 );
239 | writeReg (0 x44 , 0 x00 );
240 | writeReg (0 x45 , 0 x20 );
241 | writeReg (0 x47 , 0 x08 );
242 | writeReg (0 x48 , 0 x28 );
243 | writeReg (0 x67 , 0 x00 );
244 | writeReg (0 x70 , 0 x04 );
245 | writeReg (0 x71 , 0 x01 );
246 | writeReg (0 x72 , 0 xFE );
247 | writeReg (0 x76 , 0 x00 );
248 | writeReg (0 x77 , 0 x00 );

249
250 | writeReg (0 xFF , 0 x01 );
251 | writeReg (0 x0D , 0 x01 );

252
253 | writeReg (0 xFF , 0 x00 );
254 | writeReg (0 x80 , 0 x01 );
255 | writeReg (0 x01 , 0 xF8 );

256
257 | writeReg (0 xFF , 0 x01 );
258 | writeReg (0 x8E , 0 x01 );
259 | writeReg (0 x00 , 0 x01 );

46

260 | writeReg (0 xFF , 0 x00 );
261 | writeReg (0 x80 , 0 x00 );

262
263 | // -- VL53L0X_load_tuning_settings () end

264
265 | // " Set interrupt config to new sample ready "
266 | // -- VL53L0X_SetGpioConfig () begin

267
268 | writeReg ( SYSTEM_INTERRUPT_CONFIG_GPIO , 0 x04 );
269 | writeReg ( GPIO_HV_MUX_ACTIVE_HIGH , readReg ( GPIO_HV_MUX_ACTIVE_HIGH ) & ~0 x10 ) ; //
| active low
270 | writeReg ( SYSTEM_INTERRUPT_CLEAR , 0 x01 );

271
272 | // -- VL53L0X_SetGpioConfig () end

273
274 | measurement_timing_budget_us = getMeasurementTimingBudget () ;

275
276 | // " Disable MSRC and TCC by default "
277 | // MSRC = Minimum Signal Rate Check
278 | // TCC = Target CentreCheck
279 | // -- VL53L0X_SetSequenceStepEnable () begin

280
281 | writeReg ( SYSTEM_SEQUENCE_CONFIG , 0 xE8 );

282
283 | // -- VL53L0X_SetSequenceStepEnable () end

284
285 | // " Recalculate timing budget "
286 | setMeasurementTimingBudget ( measurement_timing_budget_us );

287
288 | // VL53L0X_StaticInit () end

289
290 | // VL53L0X_PerformRefCalibration () begin ( VL53L0X_perform_ref_calibration ())

291
292 | // -- VL53L0X_perform_vhv_calibration () begin

293
294 | writeReg ( SYSTEM_SEQUENCE_CONFIG , 0 x01 );
295 | if (! performSingleRefCalibration (0 x40 )) { return false ; }

296
297 | // -- VL53L0X_perform_vhv_calibration () end

298
299 | // -- VL53L0X_perform_phase_calibration () begin

300
301 | writeReg ( SYSTEM_SEQUENCE_CONFIG , 0 x02 );
302 | if (! performSingleRefCalibration (0 x00 )) { return false ; }

303
304 | // -- VL53L0X_perform_phase_calibration () end

305
306 | // " restore the previous Sequence Config "
307 | writeReg ( SYSTEM_SEQUENCE_CONFIG , 0 xE8 );

308
309 | // VL53L0X_PerformRefCalibration () end

310
311 | return true ;
312 | }

313
314 | // Write an 8- bit register
315 | void VL53L0X :: writeReg ( uint8_t reg , uint8_t value )
316 | {
317 | bus -> beginTransmission ( address );
318 | bus -> write ( reg ) ;
319 | bus -> write ( value );
320 | last_status = bus -> endTransmission () ;
321 | }

322
323 | // Write a 16 - bit register
324 | void VL53L0X :: writeReg16Bit ( uint8_t reg , uint16_t value )
325 | {
326 | bus -> beginTransmission ( address );

47

327 | bus -> write ( reg ) ;
328 | bus -> write (( uint8_t ) ( value >> 8) ); // value high byte
329 | bus -> write (( uint8_t ) ( value )); // value low byte
330 | last_status = bus -> endTransmission () ;
331 | }

332
333 | // Write a 32 - bit register
334 | void VL53L0X :: writeReg32Bit ( uint8_t reg , uint32_t value )
335 | {
336 | bus -> beginTransmission ( address );
337 | bus -> write ( reg ) ;
338 | bus -> write (( uint8_t ) ( value >> 24) ); // value highest byte
339 | bus -> write (( uint8_t ) ( value >> 16) );
340 | bus -> write (( uint8_t ) ( value >> | 8) ) ;
341 | bus -> write (( uint8_t ) ( value )); | // value lowest byte
342 | last_status = bus -> endTransmission () ;
343 | }

344
345 | // Read an 8- bit register
346 | uint8_t VL53L0X :: readReg ( uint8_t reg )
347 | {
348 | uint8_t value ;

349
350 | bus -> beginTransmission ( address );
351 | bus -> write ( reg ) ;
352 | last_status = bus -> endTransmission () ;

353
354 | bus -> requestFrom ( address , ( uint8_t ) 1) ;
355 | value = bus - > read () ;

356
357 | return value ;
358 | }

359
360 | // Read a 16 - bit register
361 | uint16_t VL53L0X :: readReg16Bit ( uint8_t reg )
362 | {
363 | uint16_t value ;

364
365 | bus -> beginTransmission ( address );
366 | bus -> write ( reg ) ;
367 | last_status = bus -> endTransmission () ;

368
369 | bus -> requestFrom ( address , ( uint8_t ) 2) ;
370 | value | = ( uint16_t ) bus -> read () << 8; // value high byte
371 | value |= | bus -> read () ; | // value low byte

372
373 | return value ;
374 | }

375
376 | // Read a 32 - bit register
377 | uint32_t VL53L0X :: readReg32Bit ( uint8_t reg )
378 | {
379 | uint32_t value ;

380
381 | bus -> beginTransmission ( address );
382 | bus -> write ( reg ) ;
383 | last_status = bus -> endTransmission () ;

384
385 | bus -> requestFrom ( address , ( uint8_t ) 4) ;
386 | value | = ( uint32_t ) bus -> read () << 24; // value highest byte
387 | value |= ( uint32_t ) bus -> read () << 16;
388 | value |= ( uint16_t ) bus -> read () << | 8;
389 | value |= | bus -> read () ; | // value lowest byte

390
391 | return value ;
392 | }

393
394 // Write an arbitrary number of bytes from the given array to the sensor ,

48

395 | // starting at the given register
396 | void VL53L0X :: writeMulti ( uint8_t reg , uint8_t const * src , uint8_t count )
397 | {
398 | bus -> beginTransmission ( address );
399 | bus -> write ( reg ) ;

400
401 | while ( count - - > 0)
402 | {
403 | bus -> write (*( src ++) ) ;
404 | }

405
406 | last_status = bus -> endTransmission () ;
407 | }

408
409 | // Read an arbitrary number of bytes from the sensor , starting at the given
410 | // register , into the given array
411 | void VL53L0X :: readMulti ( uint8_t reg , uint8_t * dst , uint8_t count )
412 | {
413 | bus -> beginTransmission ( address );
414 | bus -> write ( reg ) ;
415 | last_status = bus -> endTransmission () ;

416
417 | bus -> requestFrom ( address , count ) ;

418
419 | while ( count - - > 0)
420 | {
421 | *( dst ++) = bus -> read () ;
422 | }
423 | }

424
425 | // Set the return signal rate limit check value in units of MCPS ( mega counts
426 | // per second ). " This represents the amplitude of the signal reflected from the
427 | // target and detected by the device "; setting this limit presumably determines
428 | // the minimum measurement necessary for the sensor to report a valid reading .
429 | // Setting a lower limit increases the potential range of the sensor but also
430 | // seems to increase the likelihood of getting an inaccurate reading because of
431 | // unwanted reflections from objects other than the intended target .
432 | // Defaults to 0.25 MCPS as initialized by the ST API and this library .
433 | bool VL53L0X :: setSignalRateLimit ( float limit_Mcps )
434 | {
435 | if ( limit_Mcps < 0 || limit_Mcps > 511.99) { return false ; }

436
437 | // Q9 .7 fixed point format (9 integer bits , 7 fractional bits )
438 | writeReg16Bit ( FINAL_RANGE_CONFIG_MIN_COUNT_RATE_RTN_LIMIT , limit_Mcps * (1 << 7) );
439 | return true ;
440 | }

441
442 | // Get the return signal rate limit check value in MCPS
443 | float VL53L0X :: getSignalRateLimit ()
444 | {
445 | return ( float ) readReg16Bit ( FINAL_RANGE_CONFIG_MIN_COUNT_RATE_RTN_LIMIT ) / (1 << 7) ;
446 | }

447
448 | // Set the measurement timing budget in microseconds , which is the time allowed
449 | // for one measurement ; the ST API and this library take care of splitting the
450 | // timing budget among the sub - steps in the ranging sequence . A longer timing
451 | // budget allows for more accurate measurements . Increasing the budget by a
452 | // factor of N decreases the range measurement standard deviation by a factor of
453 | // sqrt (N). Defaults to about 33 milliseconds ; the minimum is 20 ms.
454 | // based on VL53L0X_set_measurement_timing_budget_micro_seconds ()
455 | bool VL53L0X :: setMeasurementTimingBudget ( uint32_t budget_us )
456 | {
457 | SequenceStepEnables enables ;
458 | SequenceStepTimeouts timeouts ;

459
460 | uint16_t const StartOverhead | = 1910;
461 | uint16_t const EndOverhead | = 960;
462 | uint16_t const MsrcOverhead | = 660;

49

463 | uint16_t const TccOverhead | = 590;
464 | uint16_t const DssOverhead | = 690;
465 | uint16_t const PreRangeOverhead | = 660;
466 | uint16_t const FinalRangeOverhead = 550;

467
468 | uint32_t used_budget_us = StartOverhead + EndOverhead ;

469
470 | getSequenceStepEnables (& enables );
471 | getSequenceStepTimeouts (& enables , & timeouts );

472
473 | if ( enables . tcc )
474 | {
475 | used_budget_us += ( timeouts . msrc_dss_tcc_us + TccOverhead ) ;
476 | }

477
478 | if ( enables . dss )
479 | {
480 | used_budget_us += 2 * ( timeouts . msrc_dss_tcc_us + DssOverhead );
481 | }
482 | else if ( enables . msrc )
483 | {
484 | used_budget_us += ( timeouts . msrc_dss_tcc_us + MsrcOverhead );
485 | }

486
487 | if ( enables . pre_range )
488 | {
489 | used_budget_us += ( timeouts . pre_range_us + PreRangeOverhead );
490 | }

491
492 | if ( enables . final_range )
493 | {
494 | used_budget_us += FinalRangeOverhead ;

495
496 | // " Note that the final range timeout is determined by the timing
497 | // budget and the sum of all other timeouts within the sequence .
498 | // If there is no room for the final range timeout , then an error
499 | // will be set . Otherwise the remaining time will be applied to
500 | // the final range ."

501
502 | if ( used_budget_us > budget_us )
503 | {
504 | // " Requested timeout too big ."
505 | return false ;
506 | }

507
508 | uint32_t final_range_timeout_us = budget_us - used_budget_us ;

509
510 | // set_sequence_step_timeout () begin
511 | // ( SequenceStepId == VL53L0X_SEQUENCESTEP_FINAL_RANGE )

512
513 | // " For the final range timeout , the pre - range timeout
514 | // | must be added . To do this both final and pre - range
515 | // | timeouts must be expressed in macro periods MClks
516 | // | because they have different vcsel periods ."

517
518 | uint32_t final_range_timeout_mclks =
519 | timeoutMicrosecondsToMclks ( final_range_timeout_us ,
520 | timeouts . final_range_vcsel_period_pclks );

521
522 | if ( enables . pre_range )
523 | {
524 | final_range_timeout_mclks += timeouts . pre_range_mclks ;
525 | }

526
527 | writeReg16Bit ( FINAL_RANGE_CONFIG_TIMEOUT_MACROP_HI ,
528 | encodeTimeout ( final_range_timeout_mclks ));

529
530 | // set_sequence_step_timeout () end

50

531
532 | measurement_timing_budget_us = budget_us ; // store for internal reuse
533 | }
534 | return true ;
535 | }

536
537 | // Get the measurement timing budget in microseconds
538 | // based on VL53L0X_get_measurement_timing_budget_micro_seconds ()
539 | // in us
540 | uint32_t VL53L0X :: getMeasurementTimingBudget ()
541 | {
542 | SequenceStepEnables enables ;
543 | SequenceStepTimeouts timeouts ;

544
545 | uint16_t const StartOverhead | = 1910;
546 | uint16_t const EndOverhead | = 960;
547 | uint16_t const MsrcOverhead | = 660;
548 | uint16_t const TccOverhead | = 590;
549 | uint16_t const DssOverhead | = 690;
550 | uint16_t const PreRangeOverhead | = 660;
551 | uint16_t const FinalRangeOverhead = 550;

552
553 | // " Start and end overhead times always present "
554 | uint32_t budget_us = StartOverhead + EndOverhead ;

555
556 | getSequenceStepEnables (& enables );
557 | getSequenceStepTimeouts (& enables , & timeouts );

558
559 | if ( enables . tcc )
560 | {
561 | budget_us += ( timeouts . msrc_dss_tcc_us + TccOverhead );
562 | }

563
564 | if ( enables . dss )
565 | {
566 | budget_us += 2 * ( timeouts . msrc_dss_tcc_us + DssOverhead ) ;
567 | }
568 | else if ( enables . msrc )
569 | {
570 | budget_us += ( timeouts . msrc_dss_tcc_us + MsrcOverhead );
571 | }

572
573 | if ( enables . pre_range )
574 | {
575 | budget_us += ( timeouts . pre_range_us + PreRangeOverhead ) ;
576 | }

577
578 | if ( enables . final_range )
579 | {
580 | budget_us += ( timeouts . final_range_us + FinalRangeOverhead );
581 | }

582
583 | measurement_timing_budget_us = budget_us ; // store for internal reuse
584 | return budget_us ;
585 | }

586
587 | // Set the VCSEL ( vertical cavity surface emitting laser ) pulse period for the
588 | // given period type (pre - range or final range ) to the given value in PCLKs .
589 | // Longer periods seem to increase the potential range of the sensor .
590 | // Valid values are ( even numbers only ):
591 | // | pre: | 12 to 18 ( initialized default : 14)
592 | // | final : 8 to 14 ( initialized default : 10)
593 | // based on VL53L0X_set_vcsel_pulse_period ()
594 | bool VL53L0X :: setVcselPulsePeriod ( vcselPeriodType type , uint8_t period_pclks )
595 | {
596 | uint8_t vcsel_period_reg = encodeVcselPeriod ( period_pclks ) ;

597
598 | SequenceStepEnables enables ;

51

599 | SequenceStepTimeouts timeouts ;

600
601 | getSequenceStepEnables (& enables );
602 | getSequenceStepTimeouts (& enables , & timeouts );

603
604 | // " Apply specific settings for the requested clock period "
605 | // "Re - calculate and apply timeouts , in macro periods "

606
607 | // " When the VCSEL period for the pre or final range is changed ,
608 | // the corresponding timeout must be read from the device using
609 | // the current VCSEL period , then the new VCSEL period can be
610 | // applied . The timeout then must be written back to the device
611 | // using the new VCSEL period .
612 | //
613 | // For the MSRC timeout , the same applies - this timeout being
614 | // dependant on the pre - range vcsel period ."

615

616
617 | if ( type == VcselPeriodPreRange )
618 | {
619 | // " Set phase check limits "
620 | switch ( period_pclks )
621 | {
622 | case 12:
623 | writeReg ( PRE_RANGE_CONFIG_VALID_PHASE_HIGH , 0 x18 ) ;
624 | break ;

625
626 | case 14:
627 | writeReg ( PRE_RANGE_CONFIG_VALID_PHASE_HIGH , 0 x30 ) ;
628 | break ;

629
630 | case 16:
631 | writeReg ( PRE_RANGE_CONFIG_VALID_PHASE_HIGH , 0 x40 ) ;
632 | break ;

633
634 | case 18:
635 | writeReg ( PRE_RANGE_CONFIG_VALID_PHASE_HIGH , 0 x50 ) ;
636 | break ;

637
638 | default :
639 | // invalid period
640 | return false ;
641 | }
642 | writeReg ( PRE_RANGE_CONFIG_VALID_PHASE_LOW , 0 x08 );

643
644 | // apply new VCSEL period
645 | writeReg ( PRE_RANGE_CONFIG_VCSEL_PERIOD , vcsel_period_reg );

646
647 | // update timeouts

648
649 | // set_sequence_step_timeout () begin
650 | // ( SequenceStepId == VL53L0X_SEQUENCESTEP_PRE_RANGE )

651
652 | uint16_t new_pre_range_timeout_mclks =
653 | timeoutMicrosecondsToMclks ( timeouts . pre_range_us , period_pclks ) ;

654
655 | writeReg16Bit ( PRE_RANGE_CONFIG_TIMEOUT_MACROP_HI ,
656 | encodeTimeout ( new_pre_range_timeout_mclks )) ;

657
658 | // set_sequence_step_timeout () end

659
660 | // set_sequence_step_timeout () begin
661 | // ( SequenceStepId == VL53L0X_SEQUENCESTEP_MSRC )

662
663 | uint16_t new_msrc_timeout_mclks =
664 | timeoutMicrosecondsToMclks ( timeouts . msrc_dss_tcc_us , period_pclks );

665
666 | writeReg ( MSRC_CONFIG_TIMEOUT_MACROP ,

52

667 | ( new_msrc_timeout_mclks > 256) ? 255 : ( new_msrc_timeout_mclks - 1) );

668
669 | // set_sequence_step_timeout () end
670 | }
671 | else if ( type == VcselPeriodFinalRange )
672 | {
673 | switch ( period_pclks )
674 | {
675 | case 8:
676 | writeReg ( FINAL_RANGE_CONFIG_VALID_PHASE_HIGH , 0 x10 );
677 | writeReg ( FINAL_RANGE_CONFIG_VALID_PHASE_LOW , | 0 x08 );
678 | writeReg ( GLOBAL_CONFIG_VCSEL_WIDTH , 0 x02 );
679 | writeReg ( ALGO_PHASECAL_CONFIG_TIMEOUT , 0 x0C );
680 | writeReg (0 xFF , 0 x01 );
681 | writeReg ( ALGO_PHASECAL_LIM , 0 x30 );
682 | writeReg (0 xFF , 0 x00 );
683 | break ;

684
685 | case 10:
686 | writeReg ( FINAL_RANGE_CONFIG_VALID_PHASE_HIGH , 0 x28 );
687 | writeReg ( FINAL_RANGE_CONFIG_VALID_PHASE_LOW , | 0 x08 );
688 | writeReg ( GLOBAL_CONFIG_VCSEL_WIDTH , 0 x03 );
689 | writeReg ( ALGO_PHASECAL_CONFIG_TIMEOUT , 0 x09 );
690 | writeReg (0 xFF , 0 x01 );
691 | writeReg ( ALGO_PHASECAL_LIM , 0 x20 );
692 | writeReg (0 xFF , 0 x00 );
693 | break ;

694
695 | case 12:
696 | writeReg ( FINAL_RANGE_CONFIG_VALID_PHASE_HIGH , 0 x38 );
697 | writeReg ( FINAL_RANGE_CONFIG_VALID_PHASE_LOW , | 0 x08 );
698 | writeReg ( GLOBAL_CONFIG_VCSEL_WIDTH , 0 x03 );
699 | writeReg ( ALGO_PHASECAL_CONFIG_TIMEOUT , 0 x08 );
700 | writeReg (0 xFF , 0 x01 );
701 | writeReg ( ALGO_PHASECAL_LIM , 0 x20 );
702 | writeReg (0 xFF , 0 x00 );
703 | break ;

704
705 | case 14:
706 | writeReg ( FINAL_RANGE_CONFIG_VALID_PHASE_HIGH , 0 x48 );
707 | writeReg ( FINAL_RANGE_CONFIG_VALID_PHASE_LOW , | 0 x08 );
708 | writeReg ( GLOBAL_CONFIG_VCSEL_WIDTH , 0 x03 );
709 | writeReg ( ALGO_PHASECAL_CONFIG_TIMEOUT , 0 x07 );
710 | writeReg (0 xFF , 0 x01 );
711 | writeReg ( ALGO_PHASECAL_LIM , 0 x20 );
712 | writeReg (0 xFF , 0 x00 );
713 | break ;

714
715 | default :
716 | // invalid period
717 | return false ;
718 | }

719
720 | // apply new VCSEL period
721 | writeReg ( FINAL_RANGE_CONFIG_VCSEL_PERIOD , vcsel_period_reg ) ;

722
723 | // update timeouts

724
725 | // set_sequence_step_timeout () begin
726 | // ( SequenceStepId == VL53L0X_SEQUENCESTEP_FINAL_RANGE )

727
728 | // " For the final range timeout , the pre - range timeout
729 | // | must be added . To do this both final and pre - range
730 | // | timeouts must be expressed in macro periods MClks
731 | // | because they have different vcsel periods ."

732
733 | uint16_t new_final_range_timeout_mclks =
734 | timeoutMicrosecondsToMclks ( timeouts . final_range_us , period_pclks );

53

735
736 | if ( enables . pre_range )
737 | {
738 | new_final_range_timeout_mclks += timeouts . pre_range_mclks ;
739 | }

740
741 | writeReg16Bit ( FINAL_RANGE_CONFIG_TIMEOUT_MACROP_HI ,
742 | encodeTimeout ( new_final_range_timeout_mclks ));

743
744 | // set_sequence_step_timeout end
745 | }
746 | else
747 | {
748 | // invalid type
749 | return false ;
750 | }

751
752 | // " Finally , the timing budget must be re - applied "

753
754 | setMeasurementTimingBudget ( measurement_timing_budget_us );

755
756 | // " Perform the phase calibration . This is needed after changing on vcsel period ."
757 | // VL53L0X_perform_phase_calibration () begin

758
759 | uint8_t sequence_config = readReg ( SYSTEM_SEQUENCE_CONFIG );
760 | writeReg ( SYSTEM_SEQUENCE_CONFIG , 0 x02 );
761 | performSingleRefCalibration (0 x0 );
762 | writeReg ( SYSTEM_SEQUENCE_CONFIG , sequence_config );

763
764 | // VL53L0X_perform_phase_calibration () end

765
766 | return true ;
767 | }

768
769 | // Get the VCSEL pulse period in PCLKs for the given period type .
770 | // based on VL53L0X_get_vcsel_pulse_period ()
771 | uint8_t VL53L0X :: getVcselPulsePeriod ( vcselPeriodType type )
772 | {
773 | if ( type == VcselPeriodPreRange )
774 | {
775 | return decodeVcselPeriod ( readReg ( PRE_RANGE_CONFIG_VCSEL_PERIOD ));
776 | }
777 | else if ( type == VcselPeriodFinalRange )
778 | {
779 | return decodeVcselPeriod ( readReg ( FINAL_RANGE_CONFIG_VCSEL_PERIOD ));
780 | }
781 | else { return 255; }
782 | }

783
784 | // Start continuous ranging measurements . If period_ms ( optional ) is 0 or not
785 | // given , continuous back -to - back mode is used (the sensor takes measurements as
786 | // often as possible ); otherwise , continuous timed mode is used , with the given
787 | // inter - measurement period in milliseconds determining how often the sensor
788 | // takes a measurement .
789 | // based on VL53L0X_StartMeasurement ()
790 | void VL53L0X :: startContinuous ( uint32_t period_ms )
791 | {
792 | writeReg (0 x80 , 0 x01 );
793 | writeReg (0 xFF , 0 x01 );
794 | writeReg (0 x00 , 0 x00 );
795 | writeReg (0 x91 , stop_variable );
796 | writeReg (0 x00 , 0 x01 );
797 | writeReg (0 xFF , 0 x00 );
798 | writeReg (0 x80 , 0 x00 );

799
800 | if ( period_ms != 0)
801 | {
802 | // continuous timed mode

54

803
804 | // VL53L0X_SetInterMeasurementPeriodMilliSeconds () begin

805
806 | uint16_t osc_calibrate_val = readReg16Bit ( OSC_CALIBRATE_VAL );

807
808 | if ( osc_calibrate_val != 0)
809 | {
810 | period_ms *= osc_calibrate_val ;
811 | }

812
813 | writeReg32Bit ( SYSTEM_INTERMEASUREMENT_PERIOD , period_ms );

814
815 | // VL53L0X_SetInterMeasurementPeriodMilliSeconds () end

816
817 | writeReg ( SYSRANGE_START , 0 x04 ); // VL53L0X_REG_SYSRANGE_MODE_TIMED
818 | }
819 | else
820 | {
821 | // continuous back -to - back mode
822 | writeReg ( SYSRANGE_START , 0 x02 ); // VL53L0X_REG_SYSRANGE_MODE_BACKTOBACK
823 | }
824 | }

825
826 | // Stop continuous measurements
827 | // based on VL53L0X_StopMeasurement ()
828 | void VL53L0X :: stopContinuous ()
829 | {
830 | writeReg ( SYSRANGE_START , 0 x01 ); // VL53L0X_REG_SYSRANGE_MODE_SINGLESHOT

831
832 | writeReg (0 xFF , 0 x01 );
833 | writeReg (0 x00 , 0 x00 );
834 | writeReg (0 x91 , 0 x00 );
835 | writeReg (0 x00 , 0 x01 );
836 | writeReg (0 xFF , 0 x00 );
837 | }

838
839 | // Returns a range reading in millimeters when continuous mode is active
840 | // ( readRangeSingleMillimeters () also calls this function after starting a
841 | // single - shot range measurement )
842 | uint16_t VL53L0X :: readRangeContinuousMillimeters ()
843 | {
844 | startTimeout () ;
845 | while (( readReg ( RESULT_INTERRUPT_STATUS ) & 0 x07 ) == 0)
846 | {
847 | if ( checkTimeoutExpired () )
848 | {
849 | did_timeout = true ;
850 | return 65535;
851 | }
852 | }

853
854 | // assumptions : Linearity Corrective Gain is 1000 ( default );
855 | // fractional ranging is not enabled
856 | uint16_t range = readReg16Bit ( RESULT_RANGE_STATUS + 10) ;

857
858 | writeReg ( SYSTEM_INTERRUPT_CLEAR , 0 x01 );

859
860 | return range ;
861 | }

862
863 | // Performs a single - shot range measurement and returns the reading in
864 | // millimeters
865 | // based on VL53L0X_PerformSingleRangingMeasurement ()
866 | uint16_t VL53L0X :: readRangeSingleMillimeters ()
867 | {
868 | writeReg (0 x80 , 0 x01 );
869 | writeReg (0 xFF , 0 x01 );
870 | writeReg (0 x00 , 0 x00 );

55

871 | writeReg (0 x91 , stop_variable );
872 | writeReg (0 x00 , 0 x01 );
873 | writeReg (0 xFF , 0 x00 );
874 | writeReg (0 x80 , 0 x00 );

875
876 | writeReg ( SYSRANGE_START , 0 x01 );

877
878 | // " Wait until start bit has been cleared "
879 | startTimeout () ;
880 | while ( readReg ( SYSRANGE_START ) & 0 x01 )
881 | {
882 | if ( checkTimeoutExpired () )
883 | {
884 | did_timeout = true ;
885 | return 65535;
886 | }
887 | }

888
889 | return readRangeContinuousMillimeters () ;
890 | }

891
892 | // Did a timeout occur in one of the read functions since the last call to
893 | // timeoutOccurred ()?
894 | bool VL53L0X :: timeoutOccurred ()
895 | {
896 | bool tmp = did_timeout ;
897 | did_timeout = false ;
898 | return tmp ;
899 | }

900
901 // Private Methods /////////////////////////////////////////////////////////////

902
903 | // Get reference SPAD ( single photon avalanche diode ) count and type
904 | // based on VL53L0X_get_info_from_device () ,
905 | // but only gets reference SPAD count and type
906 | bool VL53L0X :: getSpadInfo ( uint8_t * count , bool * type_is_aperture )
907 | {
908 | uint8_t tmp ;

909
910 | writeReg (0 x80 , 0 x01 );
911 | writeReg (0 xFF , 0 x01 );
912 | writeReg (0 x00 , 0 x00 );

913
914 | writeReg (0 xFF , 0 x06 );
915 | writeReg (0 x83 , readReg (0 x83 ) | 0 x04 );
916 | writeReg (0 xFF , 0 x07 );
917 | writeReg (0 x81 , 0 x01 );

918
919 | writeReg (0 x80 , 0 x01 );

920
921 | writeReg (0 x94 , 0 x6b );
922 | writeReg (0 x83 , 0 x00 );
923 | startTimeout () ;
924 | while ( readReg (0 x83 ) == 0 x00 )
925 | {
926 | if ( checkTimeoutExpired () ) { return false ; }
927 | }
928 | writeReg (0 x83 , 0 x01 );
929 | tmp = readReg (0 x92 );

930
931 | * count = tmp & 0 x7f ;
932 | * type_is_aperture = ( tmp >> 7) & 0 x01 ;

933
934 | writeReg (0 x81 , 0 x00 );
935 | writeReg (0 xFF , 0 x06 );
936 | writeReg (0 x83 , readReg (0 x83 ) | & ~0 x04 );
937 | writeReg (0 xFF , 0 x01 );
938 | writeReg (0 x00 , 0 x01 );

56

939
940 | writeReg (0 xFF , 0 x00 );
941 | writeReg (0 x80 , 0 x00 );

942
943 | return true ;
944 | }

945
946 | // Get sequence step enables
947 | // based on VL53L0X_GetSequenceStepEnables ()
948 | void VL53L0X :: getSequenceStepEnables ( SequenceStepEnables * enables )
949 | {
950 | uint8_t sequence_config = readReg ( SYSTEM_SEQUENCE_CONFIG );

951
952 | enables -> tcc | = ( sequence_config >> 4) & 0 x1 ;
953 | enables -> dss | = ( sequence_config >> 3) & 0 x1 ;
954 | enables -> msrc | = ( sequence_config >> 2) & 0 x1 ;
955 | enables -> pre_range | = ( sequence_config >> 6) & 0 x1 ;
956 | enables -> final_range | = ( sequence_config >> 7) & 0 x1 ;
957 | }

958
959 | // Get sequence step timeouts
960 | // based on get_sequence_step_timeout () ,
961 | // but gets all timeouts instead of just the requested one , and also stores
962 | // intermediate values
963 | void VL53L0X :: getSequenceStepTimeouts ( SequenceStepEnables const * enables ,
SequenceStepTimeouts * timeouts )
964 | {
965 | timeouts -> pre_range_vcsel_period_pclks = getVcselPulsePeriod ( VcselPeriodPreRange );

966
967 | timeouts -> msrc_dss_tcc_mclks = readReg ( MSRC_CONFIG_TIMEOUT_MACROP ) + 1;
968 | timeouts -> msrc_dss_tcc_us =
969 | timeoutMclksToMicroseconds ( timeouts -> msrc_dss_tcc_mclks ,
970 | | timeouts -> pre_range_vcsel_period_pclks ) ;

971
972 | timeouts -> pre_range_mclks =
973 | decodeTimeout ( readReg16Bit ( PRE_RANGE_CONFIG_TIMEOUT_MACROP_HI ));
974 | timeouts -> pre_range_us =
975 | timeoutMclksToMicroseconds ( timeouts -> pre_range_mclks ,
976 | | timeouts -> pre_range_vcsel_period_pclks ) ;

977
978 | timeouts -> final_range_vcsel_period_pclks =
getVcselPulsePeriod ( VcselPeriodFinalRange );

979
980 | timeouts -> final_range_mclks =
981 | decodeTimeout ( readReg16Bit ( FINAL_RANGE_CONFIG_TIMEOUT_MACROP_HI ));

982
983 | if ( enables -> pre_range )
984 | {
985 | timeouts -> final_range_mclks -= timeouts -> pre_range_mclks ;
986 | }

987
988 | timeouts -> final_range_us =
989 | timeoutMclksToMicroseconds ( timeouts -> final_range_mclks ,
990 | | timeouts -> final_range_vcsel_period_pclks );
991 | }

992
993 | // Decode sequence step timeout in MCLKs from register value
994 | // based on VL53L0X_decode_timeout ()
995 | // Note : the original function returned a uint32_t , but the return value is
996 | // always stored in a uint16_t .
997 | uint16_t VL53L0X :: decodeTimeout ( uint16_t reg_val )
998 | {
999 | // format : "( LSByte * 2^ MSByte ) + 1"
1000 | return ( uint16_t ) (( reg_val & 0 x00FF ) <<
1001 | ( uint16_t ) (( reg_val & 0 xFF00 ) >> 8) ) + 1;
1002 | }

1003
1004 // Encode sequence step timeout register value from timeout in MCLKs

57

1005 | // based on VL53L0X_encode_timeout ()
1006 | uint16_t VL53L0X :: encodeTimeout ( uint32_t timeout_mclks )
1007 | {
1008 | // format : "( LSByte * 2^ MSByte ) + 1"

1009
1010 | uint32_t ls_byte = 0;
1011 | uint16_t ms_byte = 0;

1012
1013 | if ( timeout_mclks > 0)
1014 | {
1015 | ls_byte = timeout_mclks - 1;

1016
1017 | while (( ls_byte & 0 xFFFFFF00 ) > 0)
1018 | {
1019 | ls_byte > >= 1;
1020 | ms_byte ++;
1021 | }

1022
1023 | return ( ms_byte << 8) | ( ls_byte & 0 xFF );
1024 | }
1025 | else { return 0; }
1026 | }

1027
1028 | // Convert sequence step timeout from MCLKs to microseconds with given VCSEL period
| in PCLKs
1029 | // based on VL53L0X_calc_timeout_us ()
1030 | uint32_t VL53L0X :: timeoutMclksToMicroseconds ( uint16_t timeout_period_mclks , uint8_t
| vcsel_period_pclks )
1031 | {
1032 | uint32_t macro_period_ns = calcMacroPeriod ( vcsel_period_pclks );

1033
1034 | return (( timeout_period_mclks * macro_period_ns ) + 500) / 1000;
1035 | }

1036
1037 | // Convert sequence step timeout from microseconds to MCLKs with given VCSEL period
| in PCLKs
1038 | // based on VL53L0X_calc_timeout_mclks ()
1039 | uint32_t VL53L0X :: timeoutMicrosecondsToMclks ( uint32_t timeout_period_us , uint8_t
| vcsel_period_pclks )
1040 | {
1041 | uint32_t macro_period_ns = calcMacroPeriod ( vcsel_period_pclks );

1042
1043 | return ((( timeout_period_us * 1000) + ( macro_period_ns / 2) ) / macro_period_ns ) ;
1044 | }

1045

1046
1047 | // based on VL53L0X_perform_single_ref_calibration ()
1048 | bool VL53L0X :: performSingleRefCalibration ( uint8_t vhv_init_byte )
1049 | {
1050 | writeReg ( SYSRANGE_START , 0 x01 | vhv_init_byte ); //
| VL53L0X_REG_SYSRANGE_MODE_START_STOP

1051
1052 | startTimeout () ;
1053 | while (( readReg ( RESULT_INTERRUPT_STATUS ) & 0 x07 ) == 0)
1054 | {
1055 | if ( checkTimeoutExpired () ) { return false ; }
1056 | }

1057
1058 | writeReg ( SYSTEM_INTERRUPT_CLEAR , 0 x01 );

1059
1060 | writeReg ( SYSRANGE_START , 0 x00 );

1061
1062 | return true ;
1063 | }

58

## 6.3 C++ Code for plotting

1 | # include <iostream >
2 | # include <fstream >
3 | # include <vector >
4 | # include <cmath >
5 | # include <ctime >
6 | # include <json / json .h> // JSON library
7 | # include <serial / serial .h> // Serial library
8 | # include <gnuplot - iostream .h> // GNUplot library for plotting

9
10 # define PI 3.14159265358979323846

11
12 using namespace std ;

13
14 | // Structure to hold the 3D coordinates
15 | struct Coordinate {
16 | float x;
17 | float y;
18 | float z;
19 | };

20
21 | // Function prototype for plotting 3D surface
22 | void plot3DSurface ( const vector < Coordinate >& coordinates );

23
24 | int main () {
25 | // Open the serial port
26 | serial :: Serial my_serial (" COM8 ", 9600 , serial :: Timeout :: simpleTimeout (1000) );

27
28 | // Check if the serial port is open
29 | if (! my_serial . isOpen () ) {
30 | cerr << " Failed to open serial port !" << endl ;
31 | return 1;
32 | }

33
34 | vector < Coordinate > coordinates ; // Vector to store the coordinates
35 | bool printed = false ;
36 | int printed_lines = 0;
37 | bool can_update = false ;

38
39 | // Loop to read data from the serial port
40 | while (! printed ) {
41 | string line = my_serial . readline () ; // Read a line from the serial port
42 | vector < Coordinate > temp_coords = str2list ( line ); // Convert the line to a
| list of coordinates

43
44 | // Check if the list is not empty
45 | if (! temp_coords . empty () ) {
46 | // Check if the first coordinates are zero
47 | if ( static_cast <int >( temp_coords [0]. y ) == 0 &&
| static_cast <int >( temp_coords [0]. x) == 0) {
48 | can_update = true ;
49 | }

50
51 | // Update the list of coordinates if allowed
52 | if ( can_update ) {
53 | coordinates . insert ( coordinates . end () , temp_coords . begin () ,
| temp_coords . end () ) ;
54 | printed_lines ++;

55
56 | // Once enough lines have been read , save the coordinates to a file
| and plot the surface
57 | if ( printed_lines >= 67) {
58 | ofstream outfile (" example . txt ") ;
59 | for ( const auto & coord : coordinates ) {
60 | outfile << coord .x << " " << coord .y << " " << coord .z <<
| "\n";
61 | }

59

62 | outfile . close () ;
63 | plot3DSurface ( coordinates );
64 | printed = true ;
65 | }
66 | }
67 | }
68 | }

69
70 | return 0;
71 | }

72
73 | // Function to convert a string to a list of coordinates
74 | vector < Coordinate > str2list ( const string & input_string ) {
75 | string cleaned_string = input_string ;
76 | cleaned_string . erase ( remove ( cleaned_string . begin () , cleaned_string . end () , ’\r’) ,
| cleaned_string . end () );
77 | cleaned_string . erase ( remove ( cleaned_string . begin () , cleaned_string . end () , ’\n’) ,
| cleaned_string . end () );

78
79 | vector < Coordinate > selected_dots ;
80 | size_t pos = cleaned_string . find (" aaa ");

81
82 | // Check if the string contains the prefix " aaa "
83 | if ( pos != string :: npos ) {
84 | string json_string = cleaned_string . substr ( pos + 3) ;

85
86 | // Parse the JSON string
87 | Json :: Value root ;
88 | Json :: CharReaderBuilder builder ;
89 | builder [" collectComments "] = false ;
90 | JSONCPP_STRING errs ;
91 | istringstream s( json_string );
92 | if (! parseFromStream ( builder , s , & root , & errs )) {
93 | cerr << " Error decoding JSON : " << errs << endl ;
94 | return {};
95 | }

96
97 | // Convert JSON data to a list of coordinates
98 | for ( const auto & item : root ) {
99 | float angle1 = item [0]. asFloat () * ( PI / 180) ;
100 | float angle2 = item [1]. asFloat () * ( PI / 180) ;
101 | float distance = item [2]. asFloat () ;

102
103 | float x_temp = (( distance * cos ( angle1 ) * cos ( angle2 )) + 2000) / 10;
104 | float y_temp = (( distance * cos ( angle1 ) * sin ( angle2 )) + 2000) / 10;
105 | float z_temp = (( distance * sin ( angle1 )) + 2000) / 10;

106
107 | if ( x_temp < 500 && y_temp < 500) {
108 | selected_dots . push_back ({ x_temp , y_temp , z_temp }) ;
109 | }
110 | }
111 | }

112
113 | return selected_dots ;
114 | }

115
116 | // Function to plot the 3D surface using GNUplot
117 | void plot3DSurface ( const vector < Coordinate >& coordinates ) {
118 | Gnuplot gp ;
119 | gp << " set title ’3D Surface Plot ’\n";
120 | gp << " set xlabel ’X- axis ’\n";
121 | gp << " set ylabel ’Y- axis ’\n";
122 | gp << " set zlabel ’Z- axis ’\n";
123 | gp << " splot ’-’ with points pointtype 7 pointsize 1 notitle \n";

124
125 | // Send coordinates to GNUplot
126 | gp . send1d ( boost :: make_tuple ( coordinates . begin () , coordinates . end () ,

60

127 | []( const Coordinate & coord ) { return make_tuple ( coord .x , coord .y ,
| coord .z); }) ) ;
128 | gp << "e\n";
129 | }

61

# 7 Photographs

## 7.1 Bare PCB

## Figure 48: bare PCB

## 7.2 Soldered PCB

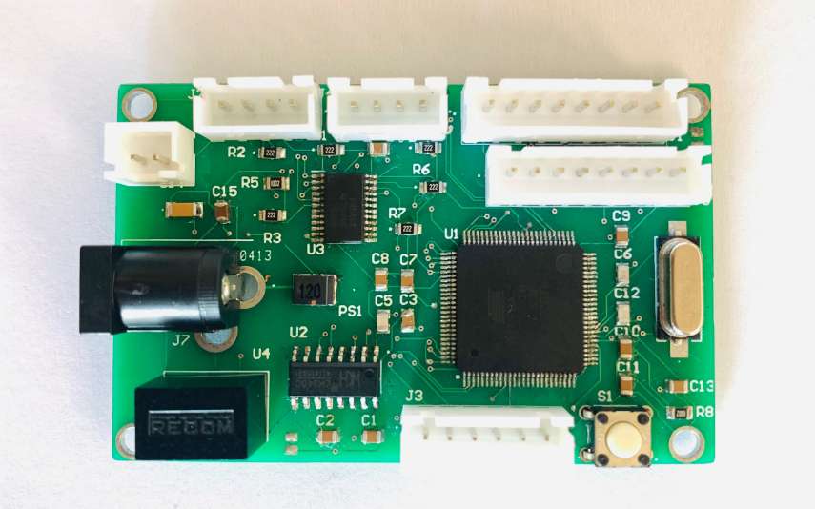
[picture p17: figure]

## Figure 49: soldered PCB

62

## 7.3 Physically Built Enclosure

## Figure 50: Enclosure

## Figure 51: Enclosure

63

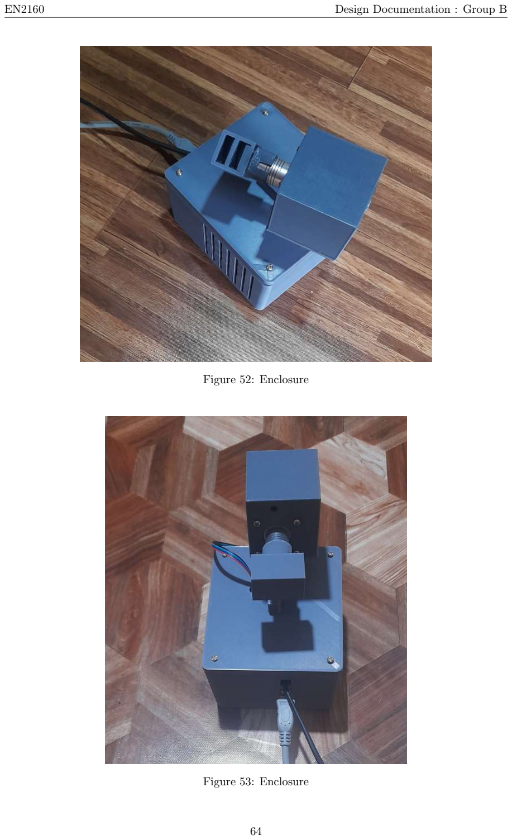
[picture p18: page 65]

## Figure 52: Enclosure

## Figure 53: Enclosure

64

## 7.4 Testing

## Figure 54: 12V supply

65

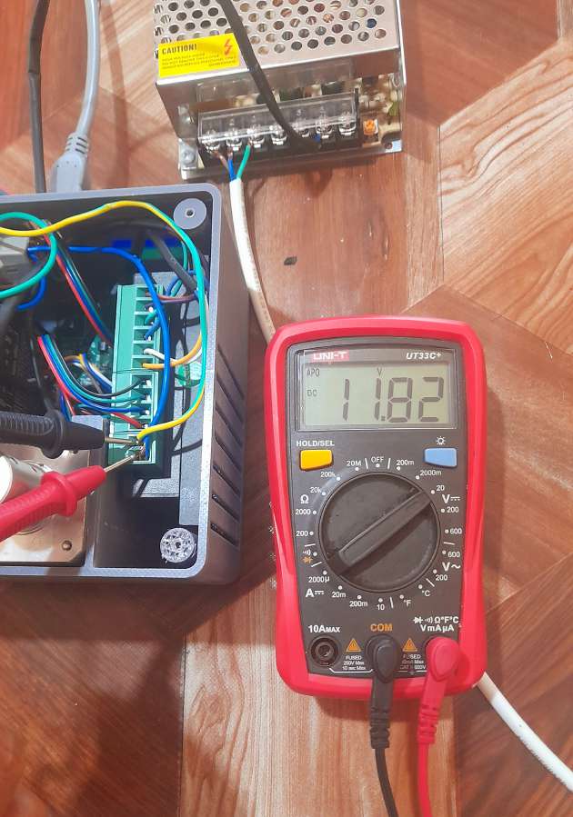
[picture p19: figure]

## Figure 55: 12V supply for motor drivers

66

## Figure 56: 5V supply for TOF sensors

67

## 7.5 System Integration

## Figure 57: System Integration

## Figure 58: System Integration

68

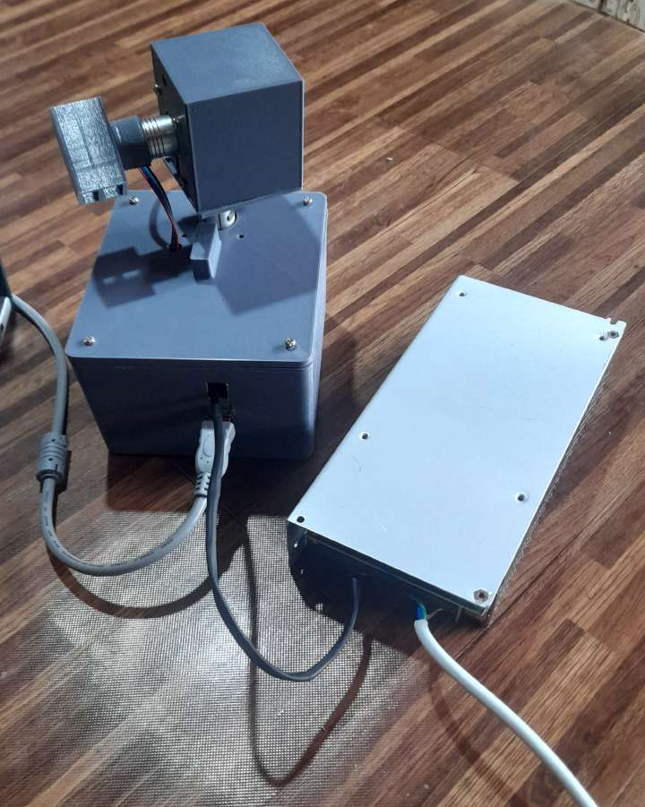
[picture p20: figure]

## Figure 59: System Integration

69

## Figure 60: 3D scanner and power supply

70

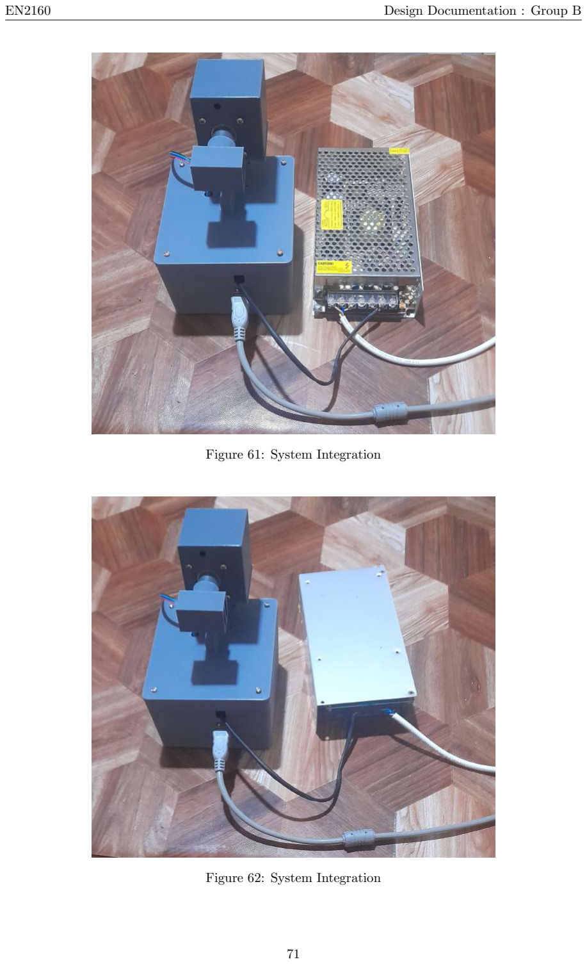
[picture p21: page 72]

## Figure 61: System Integration

## Figure 62: System Integration

71

## Figure 63: TOF sensor 1

72

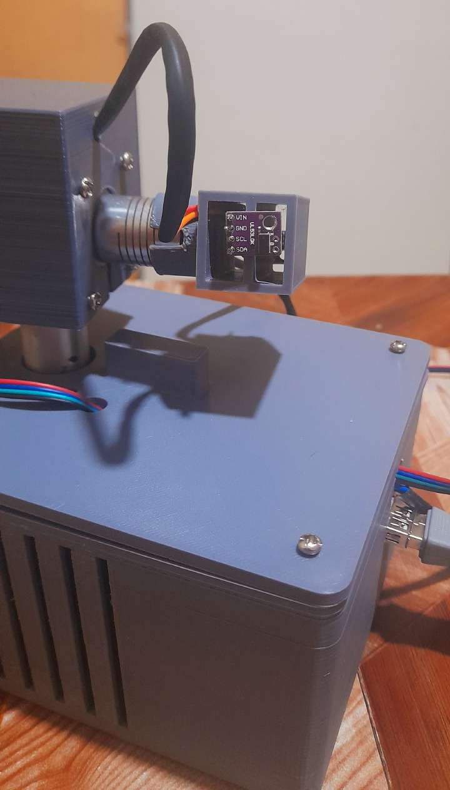
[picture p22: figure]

## Figure 64: TOF sensor 2

73

## Figure 65: inside 3D scanner

## Figure 66: inside 3D scanner

74

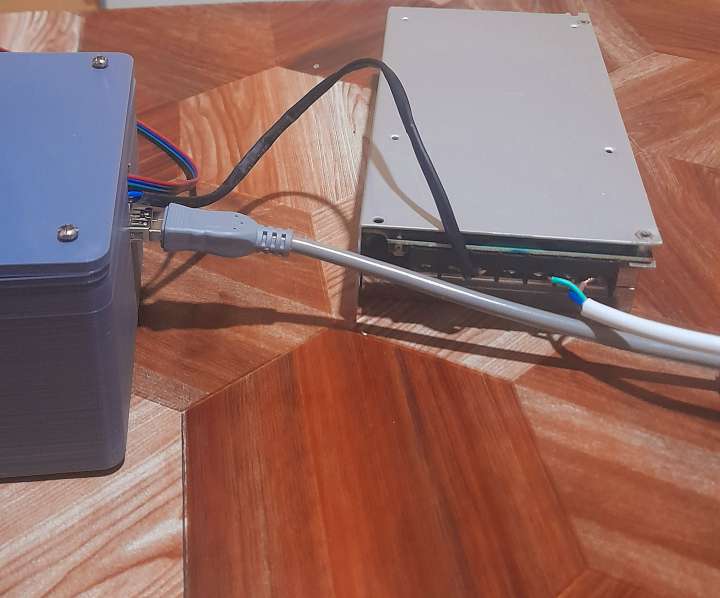
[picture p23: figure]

## Figure 67: Power Supply

75

## 7.6 Simulation Results

We created a 3D point cloud using a test data set of a box. Video Link (https://drive.google.com/file/d/10xqy0zfGPhW7z9xuLN0yOxTVgdSGbJs7/view?usp=sharing)

## Figure 68: Plotting a box

76

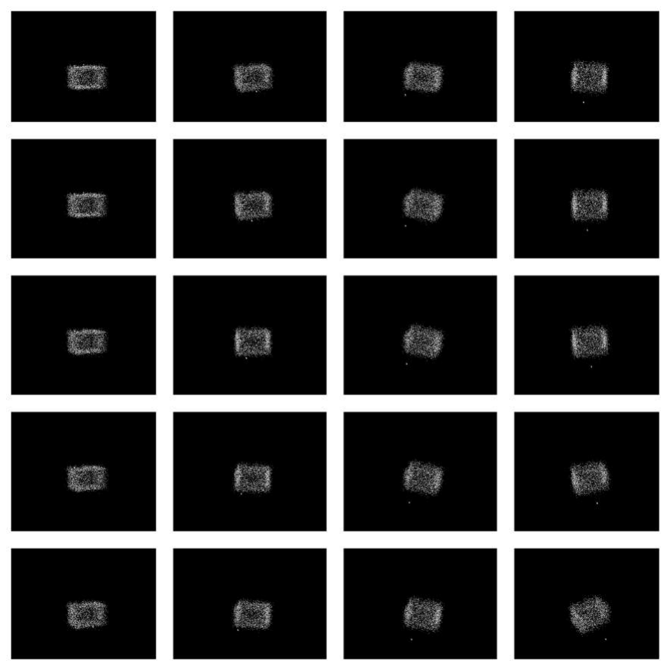
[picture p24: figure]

## Figure 69: Plotting a box

77

## Figure 70: Plotting a box

## Figure 71: Plotting a box

78

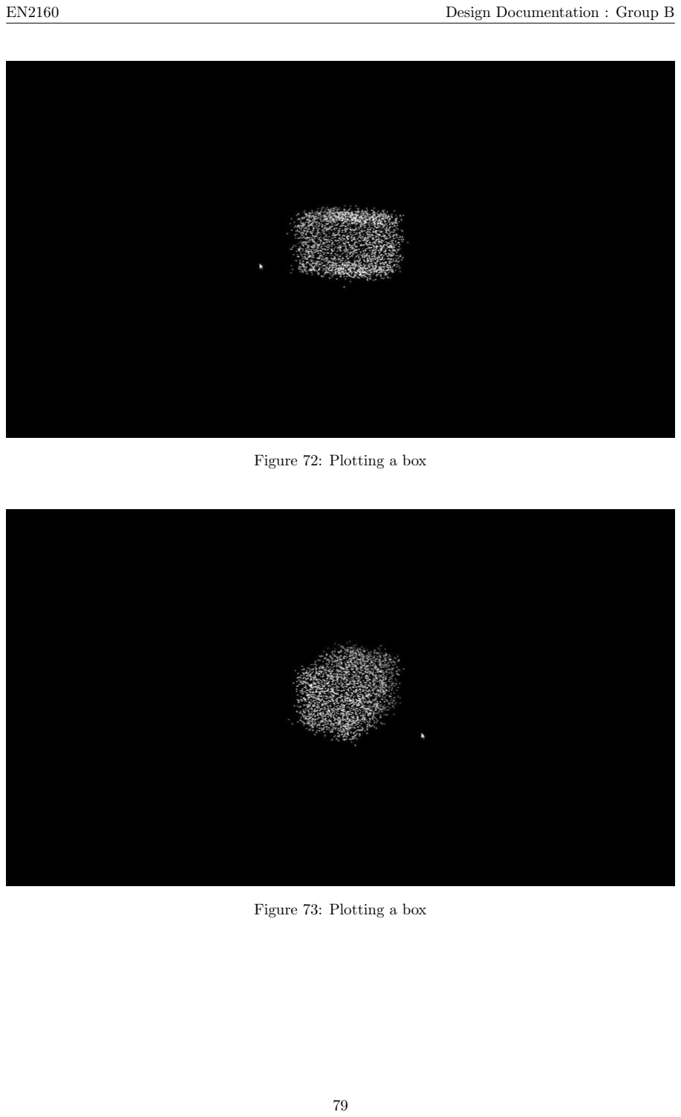
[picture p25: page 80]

## Figure 72: Plotting a box

## Figure 73: Plotting a box

79

# 8 References

## - Stefan May, David Droeschel, Dirk Holz, Christoph Wiesen, and Stefan Fuchs, ”3D pose

estimation and mapping with time-of-flight cameras,” 2008. Available at: here. (https://www.researchgate.net/publication/228662715_3D_pose_estimation_and_mapping_with_time-of-flight_cameras)

## - Stefan May, David Droeschel, Stefan Fuchs, Dirk Holz, and Andreas Nuchter, ”Robust 3D-

Mapping with Time-of-Flight Cameras,” Fraunhofer IAIS, 2009. Available at: here (https://www.researchgate.net/publication/224091092_Robust_3D-Mapping_with_Time-of-Flight_Cameras)

## - Nathan Larkin, Zeng Xi Pan, Stephen van Duin, and John Norrish, ”3D mapping using a ToF camera for self programming an industrial robot,” 2013 IEEE/ASME International Confer-

ence on Advanced Intelligent Mechatronics, Wollongong, NSW, Australia, 2013, pp. 494-499.

## Available at: here (https://doi.org/10.1109/AIM.2013.6584140)

## - Stefan May, David Droeschel, Dirk Holz, Stefan Fuchs, Ezio Malis, Andreas N¨uchter, and Joachim Hertzberg, ”Three-dimensional mapping with time-of-flight cameras,” Journal of Field Robotics, 2009. Available at: here (https://doi.org/10.1002/rob.20321)

- A. Kolb, E. Barth, and R. Koch, “ToF-sensors: New dimensions for realism and interactivity,”

## in 2008 IEEE Computer Society Conference on Computer Vision and Pattern Recognition

Workshops, Anchorage, AK, USA, 2008. Available at: here (https://doi.org/10.1109/CVPRW.2008.4563159)

80

# 9 Signed Declaration

This document, detailing the design and development process of 3D mapping device has been thor-oughly reviewed and cross-checked by an independant group to ensure accuracy and completeness.

# Cross Checked By

81

# 10 Appendix

## 10.1 Daily Log Entries

## 26 February – 3 March

## Research Phase

- Conducted Research: Reviewed extensive literature on Time-of-Flight (ToF) sensors and analyzed existing 3D scanning technologies to understand the current landscape.
- Industry Standards: Assessed prevailing industry standards and cutting-edge technologies for ToF sensors and stepper motor control in 3D scanning applications.
- System Design Decision: Based on gathered insights, decided to focus on developing a 3D scanner integrating ToF sensors, ATmega2560 microcontroller, and stepper motors for precise and efficient 3D scanning.

## 4 March – 10 March

## Conceptual Design Phase

- Brainstorming Sessions: Organized multiple brainstorming sessions to generate innovative ideas for accurately capturing 3D spatial data using ToF sensors and stepper motors.
- Concept Development: Developed several conceptual designs for the 3D scanner system, evaluating each design for functionality, precision, cost-effectiveness, and ease of implementation.

## 11 March – 17 March

## Design Evaluation Phase

- Detailed Evaluation: Conducted a comprehensive evaluation of the conceptual designs, considering technical feasibility, accuracy in 3D data acquisition, ease of assembly, serviceability, and overall performance.
- Concept Selection: After rigorous analysis and discussions, selected the most viable design for further development and prototyping.

## 18 March – 24 March

## Component Selection Phase and Feasibility Check

## - Component Analysis: Evaluated various ToF sensors for accurate distance measurement and

stepper motors for precise motion control. Reviewed options for ATmega2560 microcontrollers and PCB design components.

- Feasibility Check: Tested the integration of ToF sensors with ATmega2560 using appropriate communication protocols (e.g., I2C) to verify feasibility and performance.
- Equipment Finalization: Finalized component selection through collaborative discussions and technical assessments to ensure they meet the specific requirements of the 3D scanner project.
- Project Plan Development: Developed a detailed project plan outlining milestones, tasks, and a timeline to guide the development and testing phases of the 3D scanner prototype.

82

## 25 March – 31 March

## Design Phase

- PCB Design: Designed the PCB for the 3D scanner’s data acquisition system, ensuring compatibility with ToF sensors and ATmega2560.
- Prototype Design: Developed designs for the main unit of the 3D scanner and the mounting mechanism for ToF sensors using SolidWorks.

## 1 April – 7 April

## PCB Finalization

- PCB Finalization: Completed the final design of the PCB tailored for the 3D scanner system and sent it for manufacturing at JLC PCB.

## Initial Experiments

- Initial Experiments: Conducted preliminary experiments with ToF sensors to gather distance data and initiated basic integration tests with the ATmega2560 microcontroller.

## 15 April – 21 April

## Component Arrival & Preparation

- Component Receipt: Received ToF sensors, ATmega2560 microcontroller, and other necessary components for the 3D scanner.
- Quality Inspection: Inspected components for quality assurance and compliance with design specifications.
- Organization: Organized components to streamline the assembly process of the 3D scanner.

## 22 April – 28 April

## PCB Assembly & Soldering

- Component Placement: Started placing and soldering components on the PCB, focusing on ensuring precise connections for ToF sensors and microcontroller interfacing.
- Inspection: Used a microscope to inspect solder joints, verifying proper connections and functionality of critical components.
- Completion: Finished assembly and soldering of the PCB, followed by thorough cleaning to elim-inate flux residues. Conducted final inspections to address any potential issues.

## 29 April – 5 May

## Testing & Troubleshooting

- Initial Testing: Conducted initial power-up tests for the assembled 3D scanner system to validate basic functionality.
- Functional Testing: Performed detailed tests, including calibration of ToF sensors, validation of stepper motor control, and integration checks with the ATmega2560 microcontroller.
- Communication Verification: Ensured robust communication protocols between the 3D scanner’s components, verifying data transmission integrity and system responsiveness.

83

## 6 May – 12 May

## Final Adjustments

- Software and Hardware Adjustments: Implemented final refinements to both software algorithms (e.g., distance calculation, point cloud generation) and hardware configurations based on testing outcomes.

## Enclosure Finalization

- 3D Printing and Integration: Printed the enclosure for the 3D scanner and integrated it with the assembled PCB and wiring, ensuring secure housing and optimal sensor positioning.
- Assembly: Verified proper fit and mounting of components within the enclosure, optimizing space utilization and ensuring durability in operational environments.

## 13 May – 15 June

## Final Report Preparation

- Report Compilation: Compiled and finalized comprehensive project reports, including the Design

## Methodology Document and the Design Details Document. Detailed the entire development

process, encountered challenges, and implemented solutions for the 3D scanner.

84

## 10.2 Datasheets

## 1. Atmega2560 Microcontroller

https://ww1.microchip.com/downloads/en/devicedoc/atmel-2549-8-bit-avr-microcontroller-atmega640-1280-1281-2560-2561_datasheet.pdf (https://ww1.microchip.com/downloads/en/devicedoc/atmel-2549-8-bit-avr-microcontroller-atmega640-1280-1281-2560-2561_datasheet.pdf)

## 2. Nema 17 Stepper Motor

https://pages.pbclinear.com/rs/909-BFY-775/images/Data-Sheet-Stepper-Motor-Support. pdf (https://pages.pbclinear.com/rs/909-BFY-775/images/Data-Sheet-Stepper-Motor-Support.pdf)

## 3. TB6600-Micro Step Stepper-Motor-Driver

## https://www.watelectronics.com/tb6600-stepper-motor-driver-module/

## 4. TCA9548a I2C multiplexer

## https://www.ti.com/lit/ds/symlink/tca9548a.pdf

## 5. R 78CK 0 5-DC DC Converter

## https://www.mouser.com/datasheet/2/468/R_78CK_0_5-3310288.pdf

## 6. CH340C USB to serial chip

## https://www.mpja.com/download/35227cpdata.pdf

## 7. Crystal Oscillator 16.000 MHz

## https://www.mouser.in/datasheet/2/741/LFXTAL027946Reel-995509.pdf

85

## 10.3 Wrong Programming Approach

This method is not suitable for Professional Engineers. Arduino and Python are not industry standards.

## Distance Measurement using TOF sensor (4 March - 10 March)

## Arduino Code

1 | # include <Wire .h>
2 | # include < Adafruit_VL53L0X .h>

3
4 Adafruit_VL53L0X lox = Adafruit_VL53L0X () ;

5
6 | void setup () {
7 | Serial . begin (115200) ;

8
9 | if (! lox . begin () ) {
10 | Serial . println (F(" Failed to boot VL53L0X "));
11 | while (1) ;
12 | }

13
14 | Serial . println (F(" VL53L0X test "));
15 | }

16
17 | void loop () {
18 | VL53L0X_RangingMeasurementData_t measure ;

19
20 | lox . rangingTest (& measure , false ) ;

21
22 | if ( measure . RangeStatus != 4) { | // phase failures have incorrect data
23 | Serial . print (F(" Distance (mm): ") );
24 | Serial . println ( measure . RangeMilliMeter );
25 | } else {
26 | Serial . println (F("Out of range ")) ;
27 | }

28
29 | delay (100) ;
30 | }

## Listing 1: Arduino Code for VL53L0X Sensor

## Stepper Motor Check (11 March - 17 March)

## Arduino Code

1 | # include < AccelStepper .h>
2 | # include <Wire .h>
3 | # include < Adafruit_VL53L0X .h>

4
5 | // Define stepper motor connections
6 | # define STEP_PIN 10
7 | # define DIR_PIN 11

8
9 | # define STEP_PIN_2 12
10 | # define DIR_PIN_2 13

11
12 | # define STEPS_PER_REVOLUTION 200
13 | # define ANGLE_INCREMENT 1.8

14
15 | // Create a stepper object
16 | AccelStepper stepper ( AccelStepper :: DRIVER , STEP_PIN , DIR_PIN );
17 | AccelStepper stepper2 ( AccelStepper :: DRIVER , STEP_PIN_2 , DIR_PIN_2 );

18

86

19 | void setup () {
20 | // Set up the speed and acceleration of the stepper motor
21 | stepper . setMaxSpeed (1000) ;
22 | stepper . setAcceleration (500) ;

23
24 | stepper2 . setMaxSpeed (1000) ;
25 | stepper2 . setAcceleration (500) ;

26
27 | // Set the motor to run continuously
28 | stepper . moveTo (0) ;
29 | stepper2 . moveTo (0) ;
30 | }

31
32 | void loop () {
33 | // Run the stepper motor
34 | stepper . run () ;
35 | stepper2 . run () ;
36 | }

## Listing 2: Arduino Code for Two Stepper Motors with AccelStepper

## 3D Cloud Generation (18 March - 24 March)

## Python Code

1 | import ast
2 | import numpy as np
3 | import pyvista as pv

4
5 | # Open the file in read mode
6 | with open (’example . txt ’, ’r’) as file :
7 | # Read the file content
8 | content = file . read ()

9
10 | # Use ast . literal_eval to convert the string to a 2D list
11 | points = np . array ( ast . literal_eval ( content ))

12
13 | # Create a PolyData object
14 | cloud = pv . PolyData ( points )

15
16 | # Plot the point cloud
17 | cloud . plot ()

18
19 | # Create a 3D Delaunay triangulation of the point cloud
20 | volume = cloud . delaunay_3d ( alpha =0.6)

21
22 | # Extract the outer surface of the volume
23 | shell = volume . extract_geometry ()

24
25 | # Plot the resulting mesh
26 | shell . plot ()

## Listing 3: Python Code for 3D Delaunay Triangulation

## 2D Scan (25 March - 31 March)

## Arduino Code

1 | # include <Wire .h>
2 | # include < Adafruit_VL53L0X .h>
3 | # include <Arduino .h>
4 | # include " A4988 .h"

5
6 # define STEPS_PER_REVOLUTION 200

87

7 # define ANGLE_INCREMENT 1.8

8
9 | int Step = 10; // GPIO14 ---D5 of Nodemcu -- Step of stepper motor driver
10 | int Dire | = 11; // GPIO2 ---D4 of Nodemcu -- Direction of stepper motor driver
11 | int Sleep = 14; // GPIO12 ---D6 of Nodemcu - Control Sleep Mode on A4988
12 | int MS1 = 13; // GPIO13 - --D7 of Nodemcu - -MS1 for A4988
13 | int MS2 = 16; // GPIO16 - --D0 of Nodemcu - -MS2 for A4988
14 | int MS3 = 15; // GPIO15 - --D8 of Nodemcu - -MS3 for A4988

15
16 | // Motor Specs
17 | const int spr = 200; // Steps per revolution
18 | int RPM = 100; // Motor Speed in revolutions per minute
19 | int Microsteps = 1; // Stepsize (1 for full steps , 2 for half steps , 4 for quarter
steps , etc )

20
21 | // Providing parameters for motor control
22 | A4988 stepper ( spr , Dire , Step , MS1 , MS2 , MS3 );

23
24 | Adafruit_VL53L0X lox = Adafruit_VL53L0X () ;
25 | // Stepper stepper ( STEPS_PER_REVOLUTION , 2, 3 , 4 , 5); | // Adjust pin numbers
accordingly

26
27 | const int num_measurements = STEPS_PER_REVOLUTION ;
28 | float measurements [ num_measurements ][2];

29
30 | String arrayToString (int arr [] , int size ) {
31 | | String result = "{";
32 | for (int i = 0; i < size ; i ++) {
33 | result += String ( arr [i ]) ;
34 | | if (i < size - 1) {
35 | | result += ", ";
36 | | }
37 | }
38 | | result += "}";
39 | | return result ;
40 | }

41
42 | void setup () {
43 | | Serial . begin (9600) ;
44 | Serial1 . begin (9600) ; // Use Serial1 for communication on Arduino Mega

45
46 | pinMode ( Step , OUTPUT ); // Step pin as output
47 | pinMode ( Dire , | OUTPUT ); // Direcction pin as output
48 | pinMode ( Sleep , | OUTPUT ) ; // Set Sleep OUTPUT Control button as output
49 | digitalWrite ( Step , LOW ); // Currently no stepper motor movement
50 | | digitalWrite ( Dire , LOW );

51
52 | // Set target motor RPM to and microstepping setting
53 | // stepper . begin (RPM , Microsteps );

54
55 | | if (! lox . begin () ) {
56 | Serial . println (F(" Failed to boot VL53L0X "));
57 | | while (1) ;
58 | }

59
60 | pinMode (13 , OUTPUT ) ; | // Set pin 13 as an output

61
62 | // | stepper . setSpeed (500) ; | // Adjust the speed as needed

63
64 | Serial . println (F(" VL53L0X test with Stepper Motor "));
65 | }

66
67 | void loop () {
68 | | digitalWrite (12 , HIGH );
69 | digitalWrite ( Sleep , HIGH ) ; //A logic high allows normal operation of the A4988 by
| | removing from sleep
70 | | stepper . rotate (360) ;

71

88

72 | for (int i = 0; i < num_measurements ; i ++) {
73 | // Rotate stepper motor by ANGLE_INCREMENT degrees
74 | // | stepper . step ( ANGLE_INCREMENT );

75
76 | // Take distance measurement
77 | VL53L0X_RangingMeasurementData_t measure ;
78 | lox . rangingTest (& measure , false ) ;

79
80 | if ( measure . RangeStatus != 4) { | // phase failures have incorrect data
81 | measurements [i ][0] = i * ANGLE_INCREMENT ;
82 | measurements [i ][1] = measure . RangeMilliMeter ;
83 | } else {
84 | measurements [i ][0] = i * ANGLE_INCREMENT ;
85 | measurements [i ][1] = 10000;
86 | }

87
88 | // No delay or minimal delay between steps
89 | }

90
91 | // Print the 2D array after 360 degrees rotation
92 | Serial . print (" aaa [");
93 | for (int i = 0; i < num_measurements ; i ++) {
94 | Serial . print ("[") ;
95 | Serial . print ( measurements [ i ][0]) ;
96 | Serial . print (",") ;
97 | Serial . print ( measurements [ i ][1]) ;
98 | Serial . print ("],");
99 | }
100 | Serial . println ("]");
101 | // Serial . println ( arrayToString ());

102
103 | // Reset the stepper motor to its initial position
104 | // | stepper . step ( -360 * STEPS_PER_REVOLUTION / 360) ;
105 | digitalWrite (13 , LOW );

106
107 | // Delay before starting a new measurement
108 | delay (5000) ;
109 | }

## Listing 4: Arduino Code for VL53L0X Sensor with Stepper Motors and A4988 Driver

## 3D scan (1 April - 7 April)

## Arduino Code

1 | # include <Wire .h>
2 | # include < Adafruit_VL53L0X .h>

3
4 | # define STEP_PIN_1 8
5 | # define DIR_PIN_1 9
6 | # define ENA_PIN_1 10

7
8 | # define STEP_PIN_2 4
9 | # define DIR_PIN_2 3
10 | # define ENA_PIN_2 2

11
12 | # define XY_REV 200
13 | # define XZ_REV 50

14
15 # define ANGLE_INCREMENT 1.8

16
17 Adafruit_VL53L0X lox = Adafruit_VL53L0X () ;

18
19 float measurements [ XZ_REV ][3];

20
21 void setup () {

89

22 | Serial . begin (9600) ; | // Initialize the serial monitor

23
24 | if (! lox . begin () ) {
25 | Serial . println (F(" Failed to boot VL53L0X "));
26 | while (1) ;
27 | }
28 | pinMode (4 , OUTPUT );
29 | pinMode (3 , OUTPUT );
30 | pinMode (2 , OUTPUT );

31
32 | pinMode (7 , OUTPUT );
33 | pinMode (8 , OUTPUT );
34 | pinMode (9 , OUTPUT );

35
36 | digitalWrite ( ENA_PIN_1 , LOW );
37 | digitalWrite ( ENA_PIN_2 , LOW );

38
39 | Serial . println (F(" VL53L0X test with Stepper Motor "));
40 | }

41
42 | void loop () {
43 | // put your main code here , to run repeatedly :
44 | for (int i =0; i < XY_REV ; i ++) {
45 | if (i %2 == 0) {
46 | digitalWrite ( DIR_PIN_2 , HIGH );
47 | } else {
48 | digitalWrite ( DIR_PIN_2 , LOW );
49 | }
50 | for (int j =0; j < XZ_REV ; j ++) {
51 | VL53L0X_RangingMeasurementData_t measure ;
52 | lox . rangingTest (& measure , false ) ;

53
54 | if (i %2 == 0) {
55 | if ( measure . RangeStatus != 4) { | // phase failures have incorrect data
56 | measurements [j ][0] = j * ANGLE_INCREMENT - 45;
57 | measurements [j ][1] = i * ANGLE_INCREMENT ;
58 | measurements [j ][2] = measure . RangeMilliMeter ;
59 | } else {
60 | measurements [j ][0] = j * ANGLE_INCREMENT - 45;
61 | measurements [j ][1] = i * ANGLE_INCREMENT ;
62 | measurements [j ][2] = 10000;
63 | }
64 | } else {
65 | if ( measure . RangeStatus != 4) { | // phase failures have incorrect data
66 | measurements [ XZ_REV - j -1][0] = j * ANGLE_INCREMENT - 45;
67 | measurements [ XZ_REV - j - 1][1] = i * ANGLE_INCREMENT ;
68 | measurements [ XZ_REV - j - 1][2] = measure . RangeMilliMeter ;
69 | } else {
70 | measurements [ XZ_REV - j - 1][0] = j * ANGLE_INCREMENT - 45;
71 | measurements [ XZ_REV - j - 1][1] = i * ANGLE_INCREMENT ;
72 | measurements [ XZ_REV - j - 1][2] = 10000;
73 | }
74 | }
75 | digitalWrite ( STEP_PIN_2 , HIGH );
76 | digitalWrite ( STEP_PIN_2 , LOW ) ;
77 | }
78 | Serial . print (" aaa [");
79 | for (int k = 0; k < XZ_REV ; k ++) {
80 | Serial . print ("[") ;
81 | Serial . print ( measurements [ k ][0]) ;
82 | Serial . print (",") ;
83 | Serial . print ( measurements [ k ][1]) ;
84 | Serial . print ("],");
85 | Serial . print ( measurements [ k ][2]) ;
86 | Serial . print ("],");
87 | }
88 | Serial . println ("]");
89 | digitalWrite ( STEP_PIN_1 , HIGH );

90 digitalWrite ( STEP_PIN_1 , LOW ) ;

}

}

## Listing 5: Arduino Code for VL53L0X Sensor with Stepper Motors

## Serial Communication - Receiver (22 April - 28 April)

## Python Code

import serial
import json
from math import cos , sin , pi
import matplotlib . pyplot as plt
import numpy as np
from mpl_toolkits . mplot3d import Axes3D

from datetime import datetime

# datetime object containing current date and time now = datetime . now ()

print (" now =", now )

# dd/mm/YY H:M:S

dt_string = now . strftime ("%d/%m/%Y %H:%M:%S")

printed = False

def plot_lines ( coordinates ) :
x_values , y_values = zip (* coordinates )
plt . plot ( x_values , y_values , color =’blue ’, linestyle =’-’, linewidth =2 , label =’Line ’)

plt . title (’Graph with Connected Line (No Dots )’)
plt . xlabel (’X- axis ’)
plt . ylabel (’Y- axis ’)

# Set axis limits to always be 0 to 300 # plt . xlim (0 , 300)

# plt . ylim (0 , 300)

# Set the aspect ratio to be equal

plt . gca () . set_aspect (’equal ’, adjustable =’box ’)

plt . grid ( True )
plt . legend ()
plt . show ()

def plot_dots ( coordinates ):
x_values , y_values = zip (* coordinates )
plt . scatter ( x_values , y_values , color =’blue ’, marker =’o’) plt . title (’Graph with Dots ’)
plt . xlabel (’X- axis ’)
plt . ylabel (’Y- axis ’)

# plt . xlim (0 , 300)

# plt . ylim (0 , 300)

plt . gca () . set_aspect (’equal ’, adjustable =’box ’)

plt . grid ( True )
plt . show ()

91

55 | def plot_3d_surface ( coordinates ) :
56 | x_coords = [ coordinate [0] for coordinate in coordinates ]
57 | y_coords = [ coordinate [1] for coordinate in coordinates ]
58 | z_coords = [ coordinate [2] for coordinate in coordinates ]

59
60 | # Convert coordinates to numpy arrays
61 | x = np . array ( x_coords )
62 | y = np . array ( y_coords )
63 | z = np . array ( z_coords )

64
65 | # Create a 3D plot
66 | fig = plt . figure ()
67 | ax = fig . add_subplot (111 , projection =’3d’)

68
69 | # Plot the scatter plot
70 | ax . scatter (x , y , z , c =’b’, marker =’o’, s = 1)

71
72 | # Connect the points with lines
73 | for i in range (1 , len (x )):
74 | ax . plot ([ x[i -1] , x[ i ]] , [y[i -1] , y[ i ]] , [z[i -1] , z[ i ]] , c=’b’)

75
76 | ax . set_xlabel (’x’)
77 | ax . set_ylabel (’y’)
78 | ax . set_zlabel (’z’)

79
80 | plt . show ()

81
82 | def plot_3d_wireframe ( coordinates ):
83 | x_coords = [ coordinate [0] for coordinate in coordinates ]
84 | y_coords = [ coordinate [1] for coordinate in coordinates ]
85 | z_coords = [ coordinate [2] for coordinate in coordinates ]

86
87 | # Convert coordinates to numpy arrays
88 | x = np . array ( x_coords )
89 | y = np . array ( y_coords )
90 | z = np . array ( z_coords )

91
92 | # Create a 3D plot
93 | fig = plt . figure ()
94 | ax = fig . add_subplot (111 , projection =’3d’)

95
96 | # Plot the wireframe
97 | ax . plot_trisurf (x , y , z , linewidth =0 , antialiased = False )

98
99 | ax . set_xlabel (’x’)
100 | ax . set_ylabel (’y’)
101 | ax . set_zlabel (’z’)

102
103 | plt . show ()

104

105
106 | def str2list ( input_string ):
107 | input_string = input_string . replace (’\r’, "")
108 | input_string = input_string . replace (’\n’, "")

109
110 | temp_buffer = []
111 | temp_text = ’’
112 | selected_dots = []

113
114 | for stringData in input_string . split (’\n’):
115 | temp_buffer . append ( temp_text + stringData . split (’\n’) [0])
116 | temp_text = ’’

117
118 | if temp_buffer [ -1][:3] == " aaa ":
119 | temp_text = ’’
120 | build_temp = temp_buffer [ -1][3:]. rstrip (’\n\r,’)

121
122 | # Handle the case when the string ends with a trailing comma

92

123 | if build_temp [ -2]:
124 | build_temp = build_temp [: -2]+ build_temp [ -1]

125
126 | try :
127 | nested_list = [ list ( map (float , innerList )) for innerList in
| json . loads ( build_temp )]
128 | except json . decoder . JSONDecodeError as e :
129 | print (" Error decoding JSON :", e)
130 | print (" Problematic data :", build_temp )
131 | return False

132
133 | for nested_item in nested_list :
134 | x_temp = (( nested_item [2] * cos ( nested_item [0] * ( pi / 180) ) *
| cos ( nested_item [1] * ( pi / 180) ) ) + 2000) /10
135 | y_temp = (( nested_item [2] * cos ( nested_item [0] * ( pi / 180) ) *
| sin ( nested_item [1] * ( pi / 180) ) ) + 2000) /10
136 | z_temp = (( nested_item [2] * sin ( nested_item [0] * ( pi / 180) )) +
| 2000) /10

137
138 | if x_temp < 1000 and y_temp < 1000:
139 | selected_dots . append ([ x_temp , y_temp , z_temp ])
140 | # print (" Selected dots :" , selected_dots )
141 | return selected_dots

142
143 | return False

144

145
146 | class ReadLine :
147 | def init ( self , s) :
148 | self . buf = bytearray ()
149 | self .s = s

150
151 | def readline ( self ) :
152 | i = self . buf . find (b"\n")
153 | if i >= 0:
154 | r = self . buf [: i +1]
155 | self . buf = self . buf [i +1:]
156 | return r. decode ("utf -8")

157
158 | while True :
159 | i = max (1 , min (2048 , self .s. in_waiting ) )
160 | data = self .s . read (i)
161 | i = data . find ( b"\n")
162 | if i >= 0:
163 | r = self . buf + data [: i +1]
164 | self . buf [0:] = data [i +1:]
165 | return r. decode ("utf -8")
166 | else :
167 | self . buf . extend ( data )

168
169 | ser = serial . Serial (’COM3 ’, 9600)
170 | rl = ReadLine ( ser )

171
172 | can_update = False
173 | list_for_3d = []

174
175 | while not printed :
176 | line = rl . readline ()
177 | # print (" Received :" , line )
178 | print_temp = str2list ( line )
179 | if print_temp != False :
180 | # print ( print_temp )
181 | if ( int ( print_temp [0][1]) == 0 and int ( print_temp [0][0]) == 0) :
182 | can_update = True
183 | if True :
184 | for i in print_temp :
185 | list_for_3d . append (i)
186 | print (len ( list_for_3d ) /50)

93

187 | if len ( list_for_3d ) >= 200*50:
188 | # plot_dots ( print_temp )
189 | # plot_lines ( print_temp )
190 | # print ( len ( list_for_3d ))
191 | # Specify the file path
192 | file_path = " example " + dt_string + ". txt "

193
194 | # Open the file in write mode
195 | with open ( file_path , ’w’) as file :
196 | # Write the text to the file
197 | file . write ( str ( list_for_3d ))

198
199 | print (f" Text saved to { file_path }")
200 | # print ( list_for_3d )
201 | plot_3d_surface ( list_for_3d )
202 | printed = True

## Listing 6: Python Code for receiver

94

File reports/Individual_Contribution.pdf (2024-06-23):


# Department of Electronic & Telecommunication

Engineering,
University of Moratuwa, Sri Lanka.

# 3D Mapping Device for Object Tracking Individual Contribution - Group B

## Submitted By:

210031H Amarasinghe A.A.W.L.R.

Submitted in partial fulfillment of the requirements for the module

# EN 2160 : Electronic Design Realization

23rd June 2024

EN2160 | Individual Contribution : Group B

When collaboration is concerned, most of the tasks were done collaboratively as it is essential for both members to have experience in all aspects of the design. However, when the responsibility for the completion of each task is concerned, some parts were taken by myself.

## 1 Circuit Design

Developing the circuit for the 3D scanner was the first task I engaged in. I had to consider various needs of our product, such as the best microcontroller for this task, the best IC for USB serial communication, how to connect two TOF sensors to the microcontroller, and choosing an I2C multiplexer for independent communication of the TOF sensors. Additionally, I had to ensure that the power supply design was robust enough to handle the varying loads and that all components were properly decoupled to minimize noise and interference. This required careful selection of capacitors and inductors to ensure stable operation. After finalizing the circuit and components, I ordered the components from Mouser in Texas, USA, and LCSC Electronics in Shenzhen, China. This step was crucial to ensure that all parts were available and matched the design specifications.

## 2 PCB Design

Designing the PCB was done by me. I had to consider the thermal management of the components and the signal flow of the circuit. I tried to keep the routing paths as short as possible for the smooth operation of the PCB. I followed the IEEE guidelines and the instructions given by the lecturer when designing the PCB. Furthermore, I had to design the layout to minimize electromagnetic interference (EMI) and ensure proper grounding. This involved creating a 2-layer PCB with dedicated power and ground planes. After finalizing the PCB design, I sent the design files to JLCPCB in China for manufacturing. This involved generating the Gerber files and Bill of Materials (BOM), ensuring all files were correctly formatted and included all necessary information for the manufacturing process. I chose JLCPCB due to their high-quality manufacturing standards and quick turnaround times, which were essential for keeping our project on schedule.

## 3 Visualizer Programming

In the 3D mapper, we get distance data from the TOF sensors and send it to the computer for processing. I created a 3D mesh with the distance data using Python libraries. Then, using 3D Delaunay triangulation, I was able to make the 3D visualizer. The visualizer needed to be efficient and capable of handling large datasets in real-time, so I optimized the code for performance. Additionally, I added features such as interactive zoom, pan, and rotate, as well as the ability to save and load 3D models. This made the visualizer a useful tool for both development and demonstration purposes.

## 4 Document Preparation

We had to prepare two main documents: the design document and the design methodology report. I prepared them using LaTeX according to the required sections. The design document detailed the specifications, schematics, and design choices for the 3D scanner, while the design methodology report described the process and rationale behind our decisions. I ensured that both documents were well-structured and free of grammatical errors, and included diagrams and figures to illustrate key points. Additionally, I incorporated feedback from my collaborators to refine and improve the documents.

1

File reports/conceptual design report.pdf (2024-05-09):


# Department of Electronic & Telecommunication

Engineering,
University of Moratuwa, Sri Lanka.

# 3D Mapping Device for Object Tracking Conceptual Design Report - Group B

## Submitted By:

210728C Wijewickrama W.K.D.D.D. 210031H Amarasinghe A.A.W.L.R.

Submitted in partial fulfillment of the requirements for the module

# EN 2160 : Electronic Design Realization

7th March 2024

EN2160 | Conceptual Design Report : Group B

## Contents

1 Conceptual Designs and Functional Block Diagrams | 2
2 Comparison of Designs | 8
3 Evaluation Criteria | 9

1

## 1 Conceptual Designs and Functional Block Diagrams

### 1.1 Design 1


Figure 1: Design 1: Stage and 2 Steppers


Figure 2: Block Diagram 1

2

### 1.1.1 Overview

This innovative design merges the Time of Flight (ToF) sensor concept with the precision control of stepper motors to create a dynamic two Degrees of Freedom (2-DoF) rotational system. It incorporates two stepper motors, with one strategically positioned to govern movement along the xy plane within the base, while the other orchestrates stage rotation using z-axis angles obtained from the ToF sensor. This arrangement ensures meticulous measurement of r, θ, and α values for each reading, thereby enhancing system accuracy.

### 1.1.2 Operation

- Integration of ToF sensor technology with stepper motors for precise control.
- Two stepper motors utilized: one for xy plane movement and another for stage rotation.
- ToF sensor provides z-axis angles for enhanced control and accuracy.
- Enables meticulous measurement of r, θ, and α values for each reading.
- Data transmission facilitated through USB Type-C port, ensuring seamless connectivity and efficient data transfer.
- Advanced processing techniques applied on the computer to convert data into a comprehensive point cloud representation.
- Sophisticated image detection algorithms employed for in-depth analysis and interpretation.

### 1.1.3 Advantages

- This design offers precise control over rotational movements.
- Streamlines data processing and analysis, making it a versatile solution for diverse applications requiring precise spatial measurements and analysis.

### 1.1.4 Challenges

However, there are some challenges associated with this design:

- Mechanical Complexity: Incorporating two stepper motors and a ToF sensor system adds mechanical complexity, requiring careful calibration and maintenance to ensure reliable operation.
- Computational Requirements: Advanced processing techniques and image detection algorithms may demand significant computational power, posing challenges in terms of hardware requirements and computational efficiency.

3


### 1.2 Design 2

Figure 3: Design 2: Servo Motors and Liver System

Figure 4: Block Diagram 2

4

### 1.2.1 Overview:

Design 1 utilizes a basement housing two time-of-flight (ToF) sensors, each equipped with servo motors for precise adjustment. The servo motors enable the rotation and tilting of the basement to capture surrounding data from various angles.
Components:
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

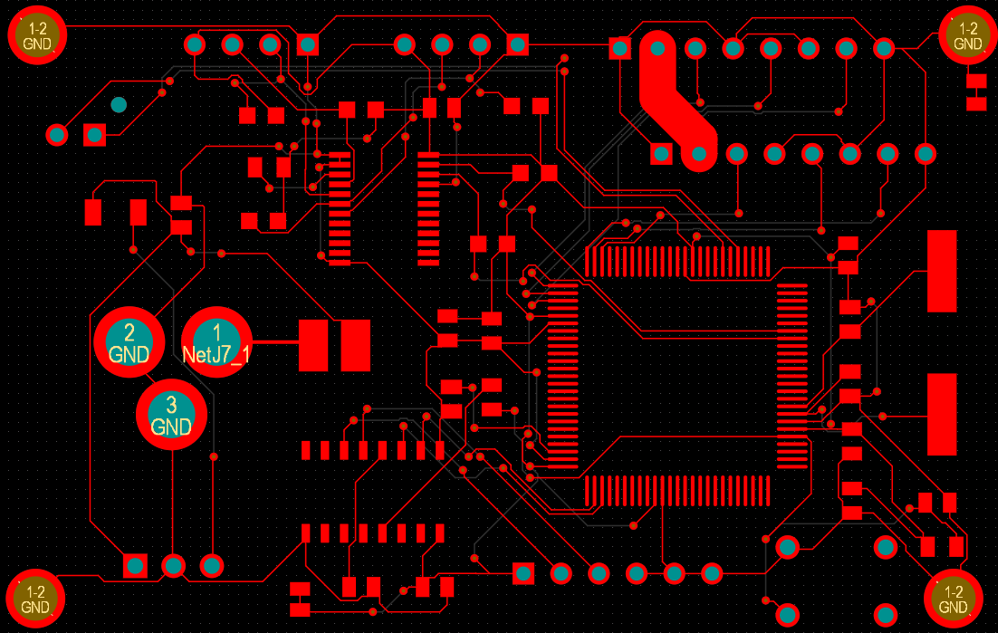
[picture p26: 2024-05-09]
PCB design/top layer.png

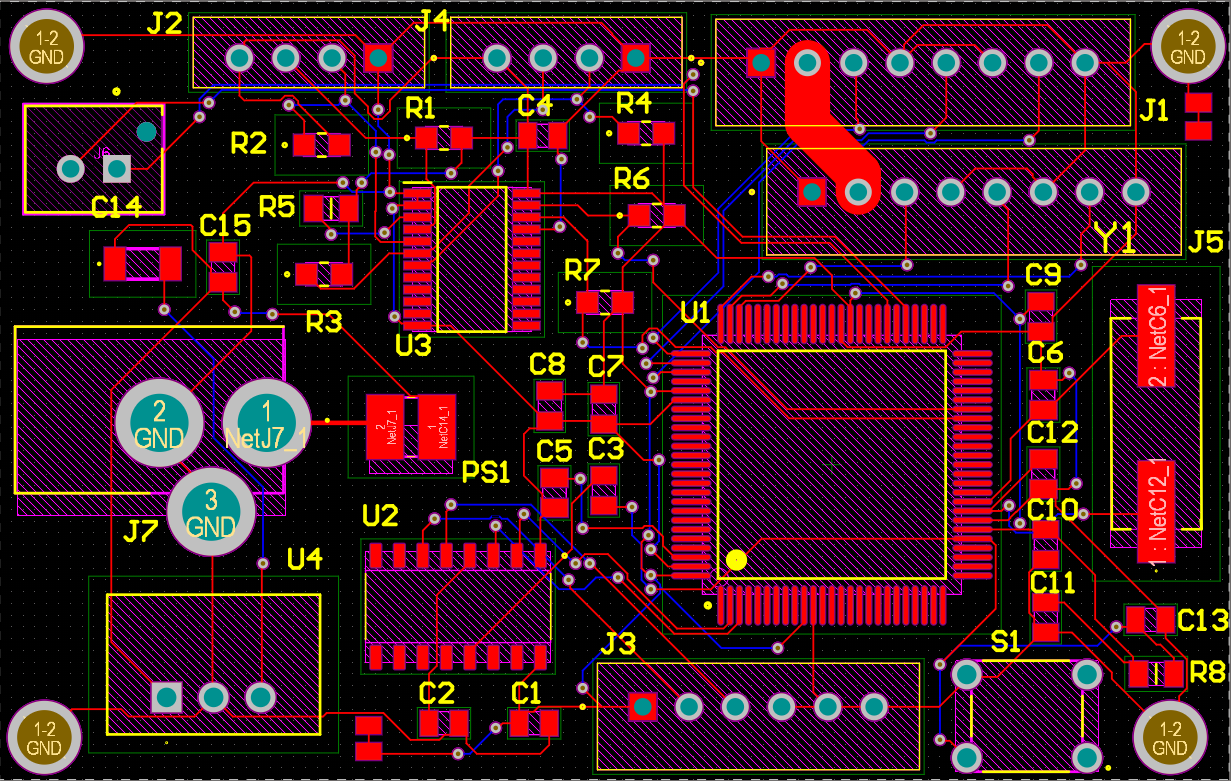
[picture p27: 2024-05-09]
PCB design/PCB.png

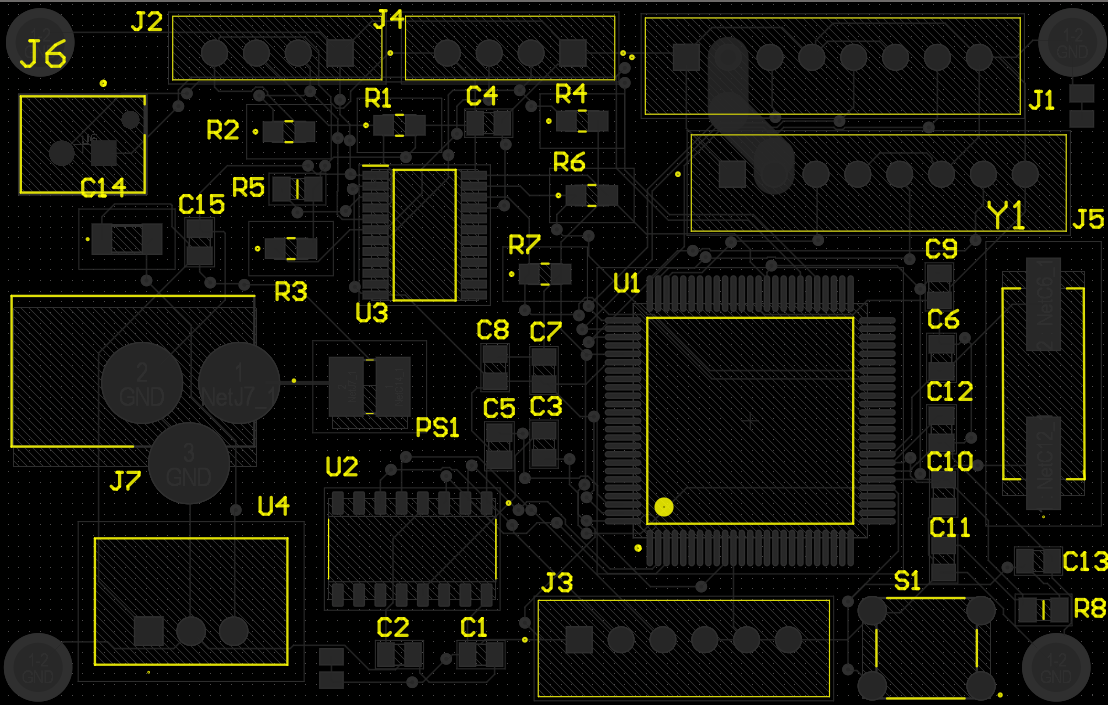
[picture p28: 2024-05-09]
PCB design/Overlay layer.png

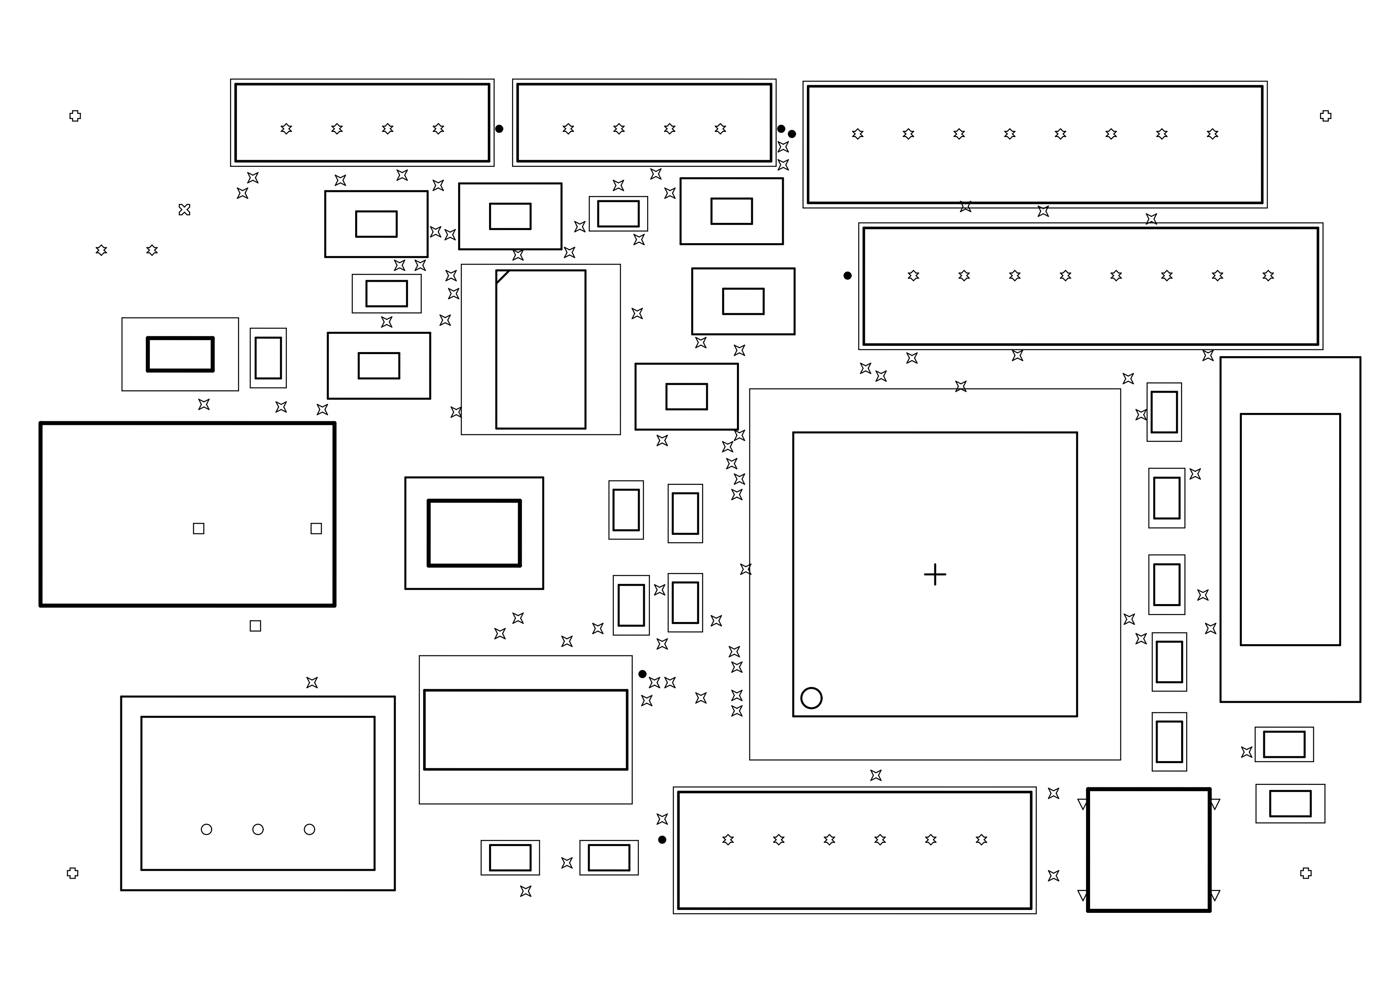
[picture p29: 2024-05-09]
PCB design/drill.jpg

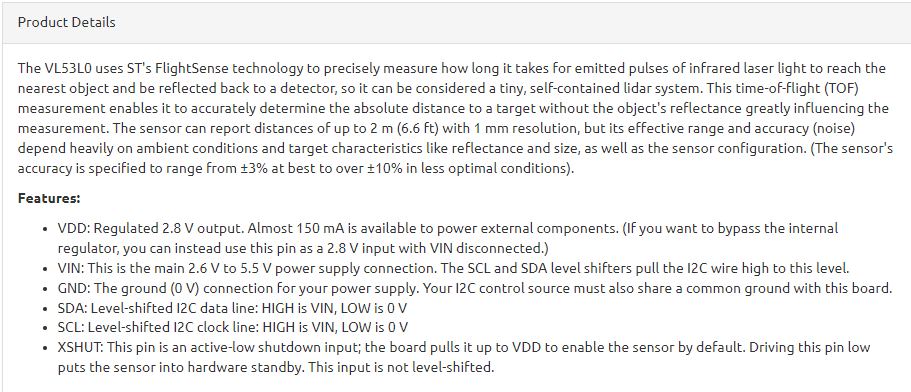
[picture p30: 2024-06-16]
data sheets/TOF.png

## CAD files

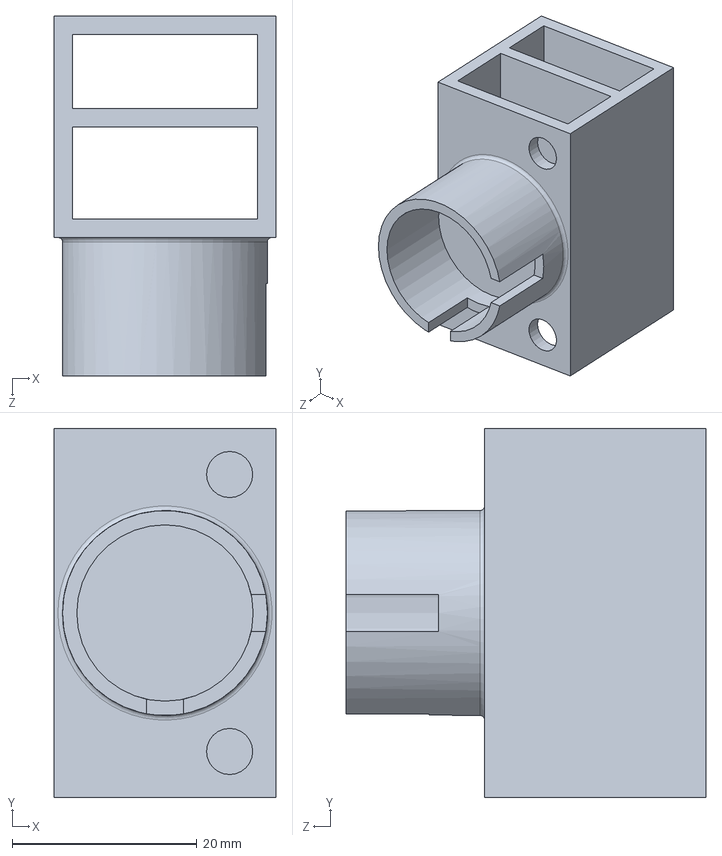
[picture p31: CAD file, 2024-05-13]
solidworks design/revolve.SLDPRT
24.0 x 40.0 x 39.0 mm

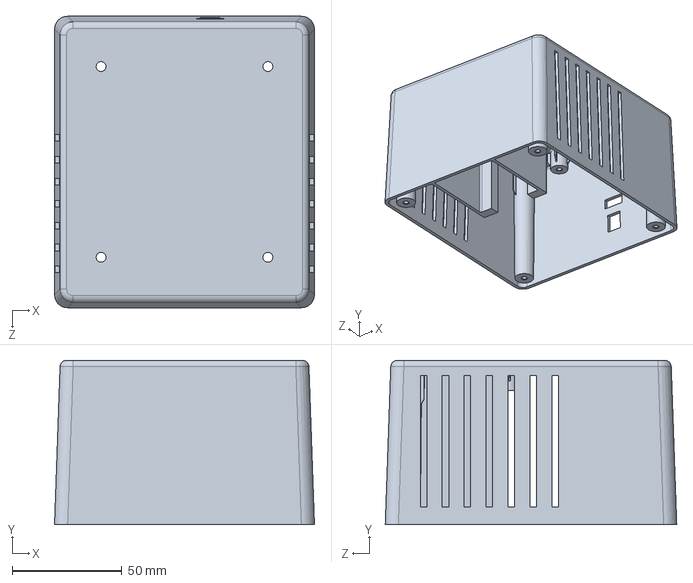
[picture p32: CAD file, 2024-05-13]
solidworks design/top.SLDPRT
118.6 x 75.0 x 133.0 mm

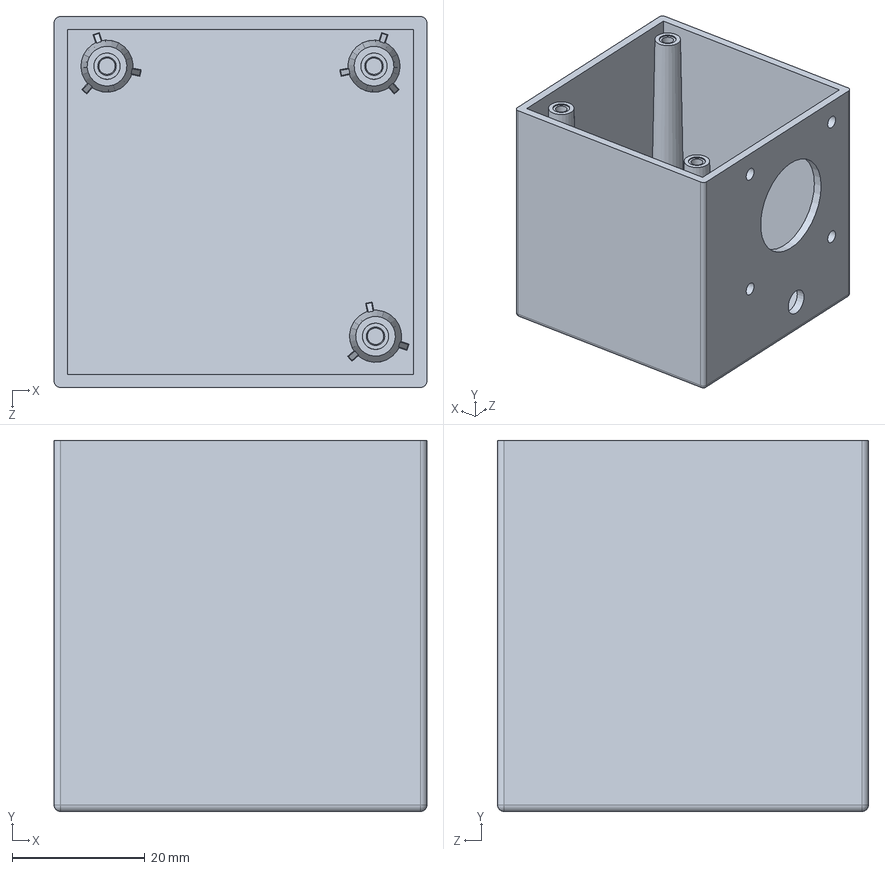
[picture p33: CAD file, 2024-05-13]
solidworks design/Toptop.SLDPRT
56.3 x 56.0 x 56.0 mm

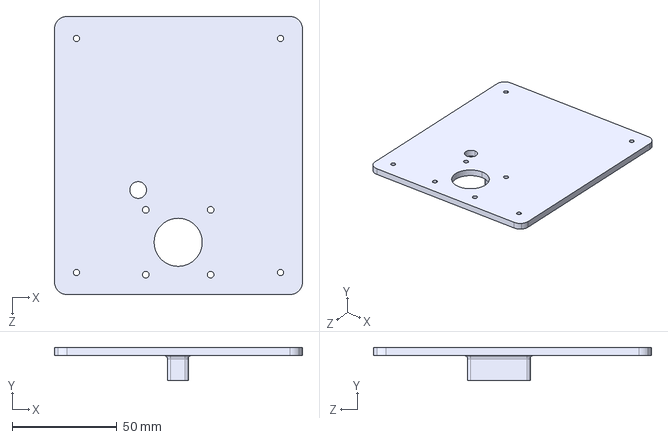
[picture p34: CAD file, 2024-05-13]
solidworks design/Bottom.STEP
118.6 x 16.0 x 133.0 mm

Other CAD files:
solidworks design/Topbottom.SLDPRT
solidworks design/Bottom.SLDPRT
solidworks design/Bottom.STL
solidworks design/Topbottom.STL
solidworks design/Toptop.STL
solidworks design/revolve.STL
solidworks design/top.STL

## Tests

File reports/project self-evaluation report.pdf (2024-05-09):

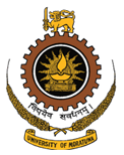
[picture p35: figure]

Department of Electronic and Telecommunication Engineering University of Moratuwa

Electronic Design Realization

210728C - Wijewickrama W.K.D.D.D.

210031H - Amarasinghe A.A.W.L.R.

# 3D Surround Scanner Project Report

## Application of Engineering Principles

During the last three semesters, we have learned various engineering principles that we applied in our project:

- Design Principles: We followed a systematic approach to design our 3D scanner. We started with a clear definition of the problem, identified the requirements, and then moved on to the design and testing phases. We also considered factors such as functionality, aesthetics, and user-friendliness in our design.
- Analytics: We used analytical methods to understand and interpret the data collected by our scanner. This helped us to make informed decisions during the design and testing phases.
- Enclosure and PCB Designing Principles: We designed a compact and robust enclosure for our scanner. We also designed a Printed Circuit Board (PCB) that houses all the electronic components of our scanner.

## Application of Mathematics and Science

We applied various mathematical and scientific concepts that we learned during our A/L and the last three semesters:

- Linear Algebra: We used linear algebra for processing the raw data collected by our scanner into a 3D image.
- Signal Processing: We used signal processing techniques to filter out noise and extract the correct data from the raw data collected by our scanner.
- Programming Skills: We used our programming skills to write the software that controls our scanner and renders the 3D image from the processed data.

- Cartesian Geometry: We used concepts from Cartesian geometry to map the data points collected by our scanner into a 3D space.

## Hands-On Skills

We applied various hands-on skills that we learned during the last three semesters:

- PCB Design, Soldering, and Testing: We designed the PCB for our scanner, soldered the components onto it, and tested it to ensure it works as expected.
- Enclosure Design: We designed a robust and user-friendly enclosure for our scanner.
- Testing and Debugging: We thoroughly tested our scanner and debugged any issues that we encountered.

## Applicability of the Project for Solving an Industrial Problem in Sri Lanka

The 3D scanner project has versatile applications in Sri Lanka's industries:

- Warehouse Management: Improves inventory tracking for better supply chain management.
- Construction: Facilitates site surveying, BIM, and construction progress monitoring for efficiency.
- Heritage Preservation: Aids in documenting and preserving cultural sites and artifacts.
- Disaster Management: Assists in terrain mapping and infrastructure assessment for better resilience.

## Cost of Main Components

The rough prices of our main components are as follows.

- 2 Nemma 17 stepper motors- Rs.3000
- Atmega 328 microcontroller- Rs.1500
- Time-of-Flight (ToF) sensor-Rs.1000
- A4988 Stepper Motor Driver-Rs.500

We use industry-level cost-effective components. The total cost of these components is within our budget.

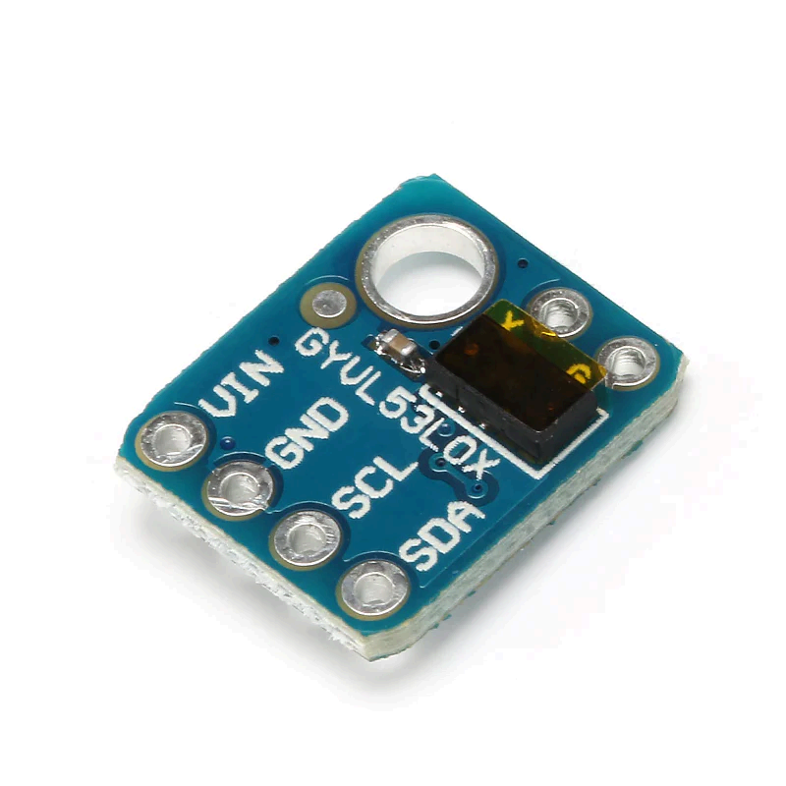
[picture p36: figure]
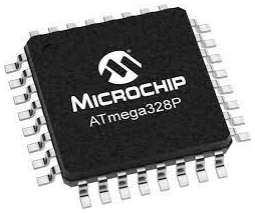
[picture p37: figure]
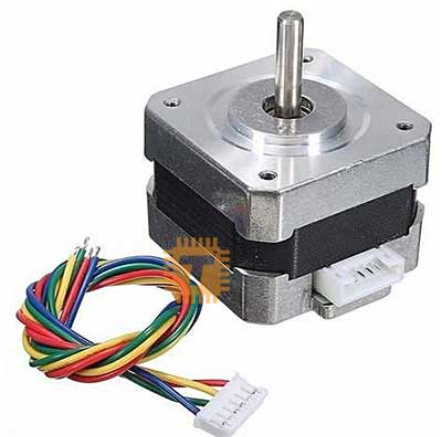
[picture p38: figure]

Fig 1 : Nema 17 Stepper Motor | Fig 2 : Atmega 328P Microcontroller | Fig 3 : Time of Flight Sensor

## Suitability of the Project to Achieve the Learning Outcomes of the Electronic Design Realization Module

Our project aligns well with the learning outcomes of the Electronic Design Realization module. We applied various engineering principles, mathematical and scientific concepts, and hands-on skills that we learned during the module. We also learned how to work as a team, manage a project, and communicate our ideas effectively. Overall, this project provided us with a valuable opportunity to apply what we learned in the module to a real-world problem.

### 1.Identify a suitable design model for a given problem:

The report indicates a systematic approach to problem definition, requirement identification, and design. This demonstrates the application of design principles to address a specific problem, which aligns with this learning outcome.

### 2.Design testable PCBs complying with industry standards:

The project involves designing a Printed Circuit Board (PCB) to house electronic components. Although the report doesn't explicitly mention compliance with industry standards, the inclusion of industry-level cost-effective components suggests adherence to certain standards and practices.

### 3.Explain testing methodologies used in electronic manufacturing:

The report mentions thorough testing and debugging of the scanner, indicating an understanding and application of testing methodologies in electronic manufacturing.

### 4.Design product enclosures complying with industry standards:

The project includes designing a robust and user-friendly enclosure, which suggests consideration for industry standards related to product enclosure design.

### 5.Prepare proper documentation for electronic design:

While the report doesn't provide explicit details about documentation, the comprehensive description of the project's development process and components used implies a level of documentation suitable for electronic design projects.

### 6.Apply the knowledge gained to a commercial design project resulting in a working prototype:

The project involves the application of engineering principles, mathematical concepts, and hands-on skills to develop a working prototype of a 3D scanner. This aligns closely with the objective of applying knowledge to a commercial design project.

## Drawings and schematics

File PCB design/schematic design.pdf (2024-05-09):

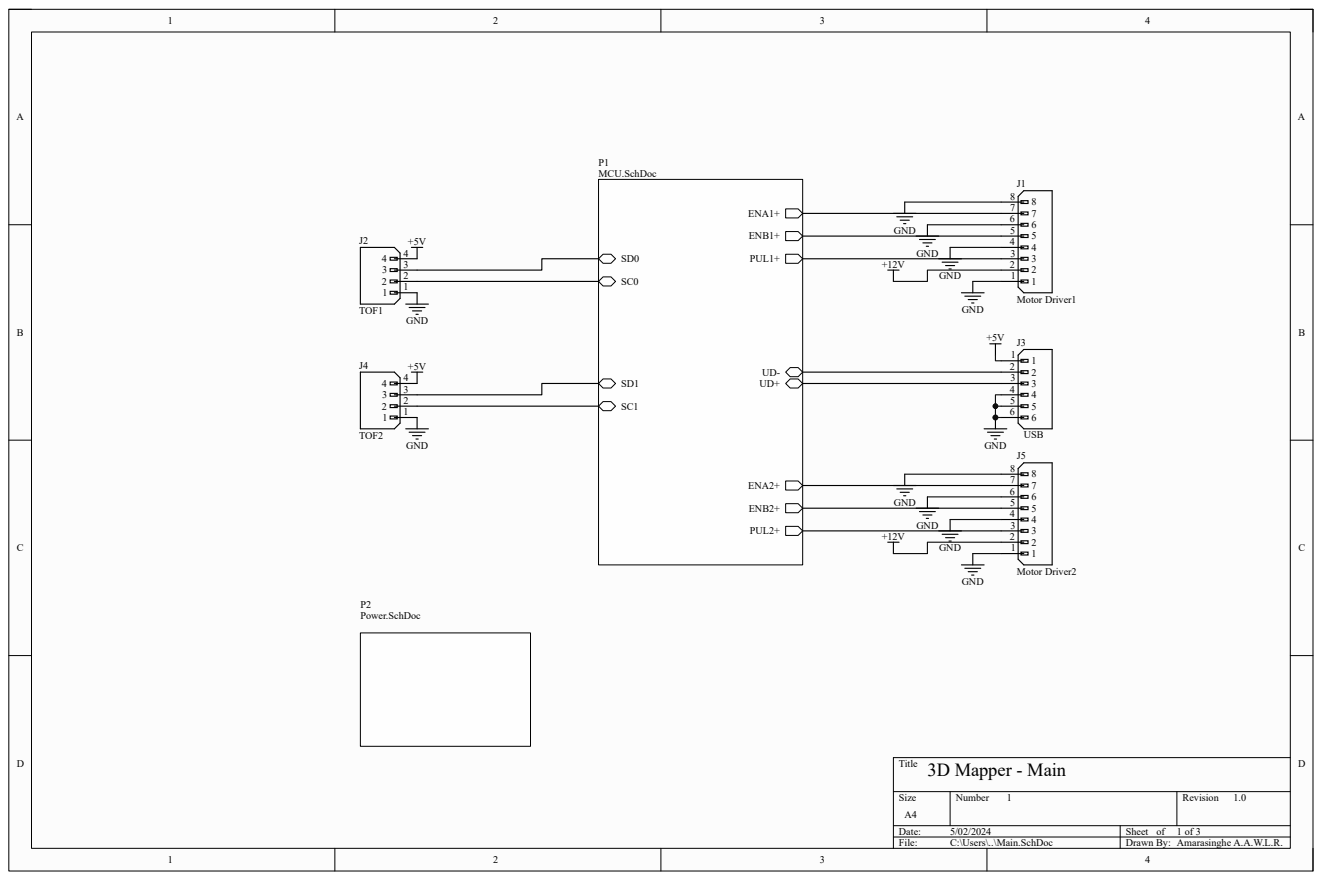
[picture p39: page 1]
Title; Size; Number; Revision; Date:; Sheet of; File:; C:\Users\..\Main.SchDoc; Drawn By:; ENA1+; PUL1+; ENB1+; ENA2+; ENB2+; PUL2+; P1 MCU.SchDoc; Motor Driver1; GND; TOF2; Amarasinghe A.A.W.L.R.; 3D Mapper - Main; TOF1; Motor Driver2; P2 Power.SchDoc; USB

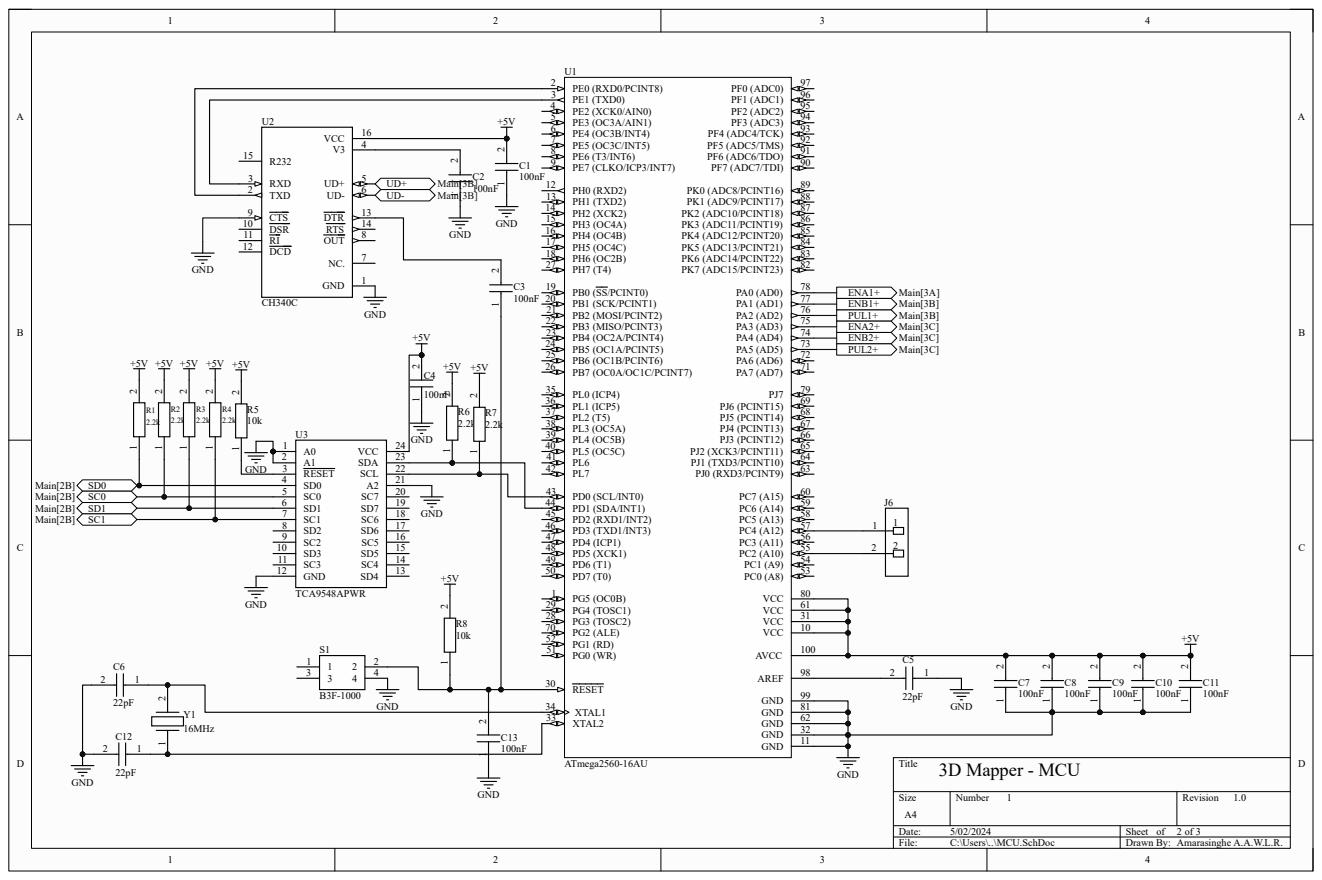
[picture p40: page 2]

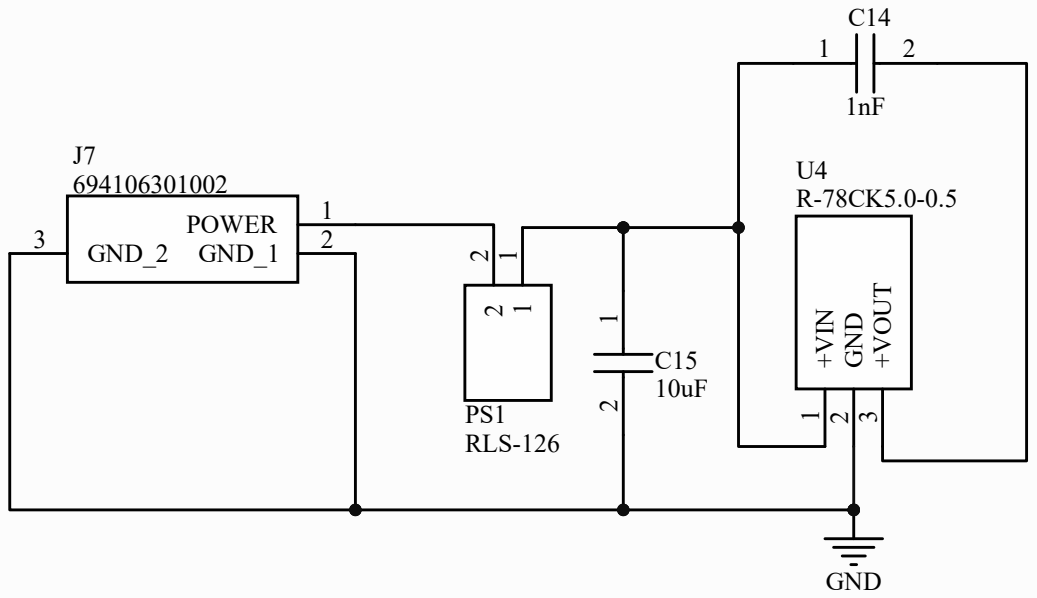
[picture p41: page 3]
Title; Size; Number; Revision; File:; C:\Users\..\Power.SchDoc; Drawn By:; 1 GND; GND ¹; PS1 RLS-126; POWER; GND_1; 2 GND_2 3

2 +VOUT
3D Mapper - Power ⁺VIN

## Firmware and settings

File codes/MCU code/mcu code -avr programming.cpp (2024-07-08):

#include <avr/io.h>
#include <util/delay.h>
#include <avr/interrupt.h>
#include "VL53L0X.h"

#define STEP_PIN_1 24
#define DIR_PIN_1 23
#define ENA_PIN_1 22

#define STEP_PIN_2 27
#define DIR_PIN_2 26
#define ENA_PIN_2 25

#define XY_REV 200
#define XZ_REV 50

#define ANGLE_INCREMENT 1.8

#define F_CPU 16000000UL // Assuming a 16 MHz clock
#define BAUD 9600
#define MYUBRR F_CPU/16/BAUD-1

#define F_SCL 100000UL // SCL frequency
#define Prescaler 1
#define TWBR_val ((((F_CPU / F_SCL) / Prescaler) - 16) / 2)

float measurements[XZ_REV][3];

void uart_init(unsigned int ubrr) {
  // Set baud rate
  UBRR0H = (unsigned char)(ubrr >> 8);
  UBRR0L = (unsigned char)ubrr;
  // Enable receiver and transmitter
  UCSR0B = (1 << RXEN0) | (1 << TXEN0);
  // Set frame format: 8 data bits, 1 stop bit
  UCSR0C = (1 << UCSZ01) | (1 << UCSZ00);
}

void uart_transmit(unsigned char data) {
  // Wait for empty transmit buffer
  while (!(UCSR0A & (1 << UDRE0)));
  // Put data into buffer, sends the data
  UDR0 = data;
}

void uart_print(const char *str) {
  while (*str) {
    uart_transmit(*str++);
  }
}

void i2c_init(void) {
  TWSR = 0x00;
  TWBR = (uint8_t)TWBR_val;
}

void i2c_start(void) {
  TWCR = (1 << TWINT) | (1 << TWSTA) | (1 << TWEN);
  while (!(TWCR & (1 << TWINT)));
}

void i2c_stop(void) {
  TWCR = (1 << TWINT) | (1 << TWSTO) | (1 << TWEN);
  while (TWCR & (1 << TWSTO));
}

void i2c_write(uint8_t data) {
  TWDR = data;
  TWCR = (1 << TWINT) | (1 << TWEN);
  while (!(TWCR & (1 << TWINT)));
}

uint8_t i2c_read_ack(void) {
  TWCR = (1 << TWINT) | (1 << TWEN) | (1 << TWEA);
  while (!(TWCR & (1 << TWINT)));
  return TWDR;
}

uint8_t i2c_read_nack(void) {
  TWCR = (1 << TWINT) | (1 << TWEN);
  while (!(TWCR & (1 << TWINT)));
  return TWDR;
}

void tof(uint8_t bus) {
  i2c_start();
  i2c_write(0x70 << 1); // TCA9548A address is 0x70
  i2c_write(1 << bus);  // send byte to select bus
  i2c_stop();
}

void setup() {
  uart_init(MYUBRR);  // Initialize the UART
  i2c_init();         // Initialize I2C

  tof(1);

  // Set pin modes using direct port manipulation
  DDRB |= (1 << DDB0) | (1 << DDB1) | (1 << DDB2); // STEP_PIN_1, DIR_PIN_1, ENA_PIN_1
  DDRB |= (1 << DDB3) | (1 << DDB4) | (1 << DDB5); // STEP_PIN_2, DIR_PIN_2, ENA_PIN_2

  // Enable pins
  PORTB &= ~(1 << PORTB2); // ENA_PIN_1 LOW
  PORTB &= ~(1 << PORTB5); // ENA_PIN_2 LOW

  // Move to the starting position
  PORTB &= ~(1 << PORTB4); // DIR_PIN_2 LOW
  for (int i = 0; i < XZ_REV / 2; i++) {
    PORTB |= (1 << PORTB3); // STEP_PIN_2 HIGH
    PORTB &= ~(1 << PORTB3); // STEP_PIN_2 LOW
    delayMicroseconds(50);
  }

  uart_print("VL53L0X test with Stepper Motor\n");
}

void loop() {
  for (int i = 0; i < XY_REV; i++) {
    if (i % 2 == 0) {
      PORTB |= (1 << PORTB4); // DIR_PIN_2 HIGH
    } else {
      PORTB &= ~(1 << PORTB4); // DIR_PIN_2 LOW
    }
    for (int j = 0; j < XZ_REV; j++) {
      i2c_start();
      i2c_write(0x29 << 1); // VL53L0X address
      i2c_write(0x00); // Register to read
      i2c_start();
      i2c_write((0x29 << 1) | 1); // Read mode
      uint8_t range = i2c_read_nack();
      i2c_stop();

      if (i % 2 == 0) {
        if (range != 255) {  // Check if range is valid
          measurements[j][0] = j * ANGLE_INCREMENT - 45;
          measurements[j][1] = i * ANGLE_INCREMENT;
          measurements[j][2] = range;
        } else {
          measurements[j][0] = j * ANGLE_INCREMENT - 45;
          measurements[j][1] = i * ANGLE_INCREMENT;
          measurements[j][2] = 10000;
        }
      } else {
        if (range != 255) {  // Check if range is valid
          measurements[XZ_REV - j - 1][0] = j * ANGLE_INCREMENT - 45;
          measurements[XZ_REV - j - 1][1] = i * ANGLE_INCREMENT;
          measurements[XZ_REV - j - 1][2] = range;
        } else {
          measurements[XZ_REV - j - 1][0] = j * ANGLE_INCREMENT - 45;
          measurements[XZ_REV - j - 1][1] = i * ANGLE_INCREMENT;
          measurements[XZ_REV - j - 1][2] = 10000;
        }
      }
      PORTB |= (1 << PORTB3); // STEP_PIN_2 HIGH
      PORTB &= ~(1 << PORTB3); // STEP_PIN_2 LOW
    }
    uart_print("aaa[");
    for (int k = 0; k < XZ_REV; k++) {
      uart_transmit('[');
      uart_print(measurements[k][0]);
      uart_transmit(',');
      uart_print(measurements[k][1]);
      uart_transmit(',');
      uart_print(measurements[k][2]);
      uart_transmit(']');
      if (k < XZ_REV - 1) uart_transmit(',');
    }
    uart_print("]\n");
    PORTB |= (1 << PORTB0); // STEP_PIN_1 HIGH
    PORTB &= ~(1 << PORTB0); // STEP_PIN_1 LOW
  }
}

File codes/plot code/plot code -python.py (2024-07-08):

import serial
import json
from math import cos, sin, pi
import matplotlib.pyplot as plt
import numpy as np
from mpl_toolkits.mplot3d import Axes3D

from datetime import datetime

# datetime object containing current date and time
now = datetime.now()
 
print("now =", now)

# dd/mm/YY H:M:S
dt_string = now.strftime("%d/%m/%Y %H:%M:%S")

printed = False

def plot_lines(coordinates):
    x_values, y_values = zip(*coordinates)
    plt.plot(x_values, y_values, color='blue', linestyle='-', linewidth=2, label='Line')

    plt.title('Graph with Connected Line (No Dots)')
    plt.xlabel('X-axis')
    plt.ylabel('Y-axis')

    # Set axis limits to always be 0 to 300
    #plt.xlim(0, 300)
    #plt.ylim(0, 300)

    # Set the aspect ratio to be equal
    plt.gca().set_aspect('equal', adjustable='box')

    plt.grid(True)
    plt.legend()
    plt.show()

def plot_dots(coordinates):
    x_values, y_values = zip(*coordinates)
    plt.scatter(x_values, y_values, color='blue', marker='o')
    plt.title('Graph with Dots')
    plt.xlabel('X-axis')
    plt.ylabel('Y-axis')

    #plt.xlim(0, 300)
    #plt.ylim(0, 300)

    plt.gca().set_aspect('equal', adjustable='box')

    plt.grid(True)
    plt.show()


def plot_3d_surface(coordinates):
    x_coords = [coordinate[0] for coordinate in coordinates]
    y_coords = [coordinate[1] for coordinate in coordinates]
    z_coords = [coordinate[2] for coordinate in coordinates]

    # Convert coordinates to numpy arrays
    x = np.array(x_coords)
    y = np.array(y_coords)
    z = np.array(z_coords)

    # Create a 3D plot
    fig = plt.figure()
    ax = fig.add_subplot(111, projection='3d')

    # Plot the scatter plot
    ax.scatter(x, y, z, c='b', marker='o', s = 1)

    # Connect the points with lines
    for i in range(1, len(x)):
        ax.plot([x[i-1], x[i]], [y[i-1], y[i]], [z[i-1], z[i]], c='b')

    ax.set_xlabel('x')
    ax.set_ylabel('y')
    ax.set_zlabel('z')

    plt.show()

def plot_3d_wireframe(coordinates):
    x_coords = [coordinate[0] for coordinate in coordinates]
    y_coords = [coordinate[1] for coordinate in coordinates]
    z_coords = [coordinate[2] for coordinate in coordinates]

    # Convert coordinates to numpy arrays
    x = np.array(x_coords)
    y = np.array(y_coords)
    z = np.array(z_coords)

    # Create a 3D plot
    fig = plt.figure()
    ax = fig.add_subplot(111, projection='3d')

    # Plot the wireframe
    ax.plot_trisurf(x, y, z, linewidth=0, antialiased=False)

    ax.set_xlabel('x')
    ax.set_ylabel('y')
    ax.set_zlabel('z')

    plt.show()


def str2list(input_string):
    input_string = input_string.replace('\r', "")
    input_string = input_string.replace('\n', "")
    
    temp_buffer = []
    temp_text = ''
    selected_dots = []

    for stringData in input_string.split('\n'):
        temp_buffer.append(temp_text + stringData.split('\n')[0])
        temp_text = ''

        if temp_buffer[-1][:3] == "aaa":
            temp_text = ''
            build_temp = temp_buffer[-1][3:].rstrip('\n\r,')
            
            # Handle the case when the string ends with a trailing comma
            if build_temp[-2]:
                build_temp = build_temp[:-2]+build_temp[-1]

            try:
                nested_list = [list(map(float, innerList)) for innerList in json.loads(build_temp)]
            except json.decoder.JSONDecodeError as e:
                print("Error decoding JSON:", e)
                print("Problematic data:", build_temp)
                return False
            
            for nested_item in nested_list:
                x_temp = ((nested_item[2] * cos(nested_item[0] * (pi / 180)) * cos(nested_item[1] * (pi / 180))) + 2000) /10
                y_temp = ((nested_item[2] * cos(nested_item[0] * (pi / 180)) * sin(nested_item[1] * (pi / 180))) + 2000) /10
                z_temp = ((nested_item[2] * sin(nested_item[0] * (pi / 180))) + 2000) /10
                
                if x_temp < 500 and y_temp < 500:
                    selected_dots.append([x_temp, y_temp,z_temp])

            #print("Selected dots:", selected_dots)
            return selected_dots

    return False


class ReadLine:
    def __init__(self, s):
        self.buf = bytearray()
        self.s = s

    def readline(self):
        i = self.buf.find(b"\n")
        if i >= 0:
            r = self.buf[:i+1]
            self.buf = self.buf[i+1:]
            return r.decode("utf-8")
        
        while True:
            i = max(1, min(2048, self.s.in_waiting))
            data = self.s.read(i)
            i = data.find(b"\n")
            if i >= 0:
                r = self.buf + data[:i+1]
                self.buf[0:] = data[i+1:]
                return r.decode("utf-8")
            else:
                self.buf.extend(data)

ser = serial.Serial('COM8', 9600)
rl = ReadLine(ser)

can_update = False
list_for_3d = []
printed_lines = 0

while not printed:
    line = rl.readline()
    #print("Received:", line)
    print_temp = str2list(line)
    if print_temp != False:
        #print(print_temp)
        if (int(print_temp[0][1]) == 0 and int(print_temp[0][0]) == 0):
            can_update = True
        if True:
            for i in print_temp:
                list_for_3d.append(i)
            print(printed_lines)
            printed_lines += 1
            if printed_lines >= 67:
                #plot_dots(print_temp)
                #plot_lines(print_temp)
                #print(len(list_for_3d))
                # Specify the file path
                file_path = "example"  + ".txt"

                # Open the file in write mode
                with open(file_path, 'w') as file:

                    # Write the text to the file
                    file.write(str(list_for_3d))

                print(f"Text saved to {file_path}")
                #print(list_for_3d)
                plot_3d_surface(list_for_3d)
                printed = True

        
